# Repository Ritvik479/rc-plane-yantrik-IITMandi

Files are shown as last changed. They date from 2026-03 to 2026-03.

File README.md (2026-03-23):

# ✈️ Garuda 2.0 — RC Plane Design

> Fixed-wing RC aircraft designed for payload delivery, built by **Team Garuda** under the **Yantrik Club, IIT Mandi**.

---

## 📌 Overview

Garuda 2.0 is a high-wing monoplane with a conventional tail, designed for stability and payload delivery. The design philosophy prioritizes a balance between payload capacity and structural rigidity. The **CH-10 airfoil** was selected for its superior lift characteristics at low speeds, and the streamlined rectangular fuselage minimizes drag while housing a 250g cube payload internally.

Visit Official Webpage at : https://remandey.github.io/yantrik-rcplane/

---

## 📐 Technical Specifications

### Dimensions

| Component | Parameter | Value |
|---|---|---|
| **Wing** | Span | 1.18 m |
| **Wing** | Chord | 0.28 m |
| **Wing** | Dihedral | 3° |
| **Fuselage** | Length | 0.9 m |
| **Fuselage** | Width × Height | 0.13 m × 0.13 m |
| **Horizontal Tail** | Span | 0.52 m |
| **Horizontal Tail** | MAC | 0.1305 m |
| **Vertical Tail** | Height | 0.19 m |
| **Vertical Tail** | MAC | 0.0963 m |
| **All-Up Weight** | (without payload) | ~921 g |

### Propulsion System

| Component | Specification | Justification |
|---|---|---|
| Motor | 1500 KV BLDC | High torque for cargo lift |
| ESC | 40A Brushless | Reliable current handling for 3S |
| Battery | 3S LiPo, 2200 mAh (11.1V) | Optimal weight-to-energy ratio |
| Propeller | 1100 × 6 | Matched to motor KV and 3S voltage |

---

## 📊 Design Calculations

| Parameter | Value |
|---|---|
| **Airfoil** | CH-10 |
| **Thrust-to-Weight Ratio** | 1.1 (with payload) / 0.9 (without payload) |
| **Wing Loading** | ~4.19 kg/m² (~41 N/m²) |
| **CG Position** | 25–30% of wing MAC (70–84 mm from LE) |
| **Static Margin** | ~10% (positive longitudinal stability) |

---

## 📦 Payload System

- **Payload:** 250g cube, housed in a balsa cage centered at the CG
- **Drop Mechanism:** RC-operated trap door driven by a high-torque 9g servo
- **Retention:** Push springs at the roof of the cage for smooth ejection

The payload bay is positioned exactly at the aircraft's CG to ensure flight stability is unaffected during and after the drop.

---

## 🧱 Materials & Construction

| Part | Material |
|---|---|
| Fuselage skin | Depron foam |
| Wing ribs | Laser-cut Balsa |
| Wing main spar | Balsa wood (bending stiffness) |
| Wing mounting | Rubber bands (crash-repair friendly) |

---

## 🛠️ Tools & Software

| Tool | Purpose |
|---|---|
| [SolidWorks](https://www.solidworks.com/) | 3D CAD modelling of airframe and components |
| [OpenVSP](http://openvsp.org/) | Aerodynamic geometry and performance analysis |
| [XFLR5](http://www.xflr5.tech/xflr5.htm) | Airfoil selection and wing aerodynamics |

---

## 📸 Construction Photos & CAD Files

📁 [Google Drive — Photos & CAD](https://drive.google.com/drive/folders/1Txp1gwdNweSBexzmWJwU87oO0N__N0AG?usp=sharing)

---

## 🤝 Acknowledgements

Developed under the **Yantrik Club** at **IIT Mandi** .

---

## 📄 License

This project is intended for academic and educational use.  
© Team Garuda — Yantrik Club, IIT Mandi

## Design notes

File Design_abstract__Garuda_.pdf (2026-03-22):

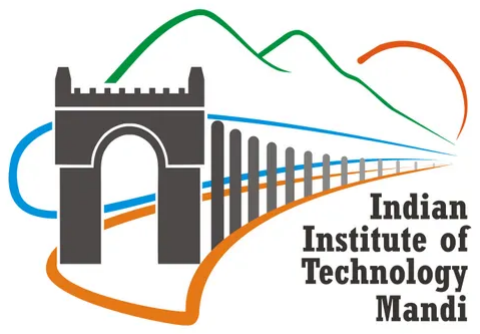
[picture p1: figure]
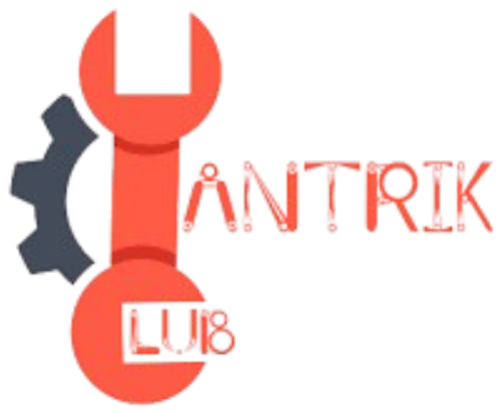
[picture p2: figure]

# DESIGN REPORT : TEAM GARUDA

Team Name: Garuda

Aircraft Name: Garuda 2.0

Team member details

Name | Phone no. | Email ID | Institution
Advaith S. Pillai (Leader) | 8108560164 | b25314@students.iit-mandi.ac.in | IIT Mandi
Reman Dey | 9674300416 | b25331@students.iit-mandi.ac.in | IIT Mandi
Rishi Kurup | 7306000420 | b25394@students.iit-mandi.ac.in | IIT Mandi
Gaurav Gupta | 9835510837 | b25453@students.iit-mandi.ac.in

IIT Mandi

Team Leader Email: b25314@students.iitmandi.ac.in

Team Leader Phone Number: 8108560164

Contents

1 Design Overview | 1
2 Technical Specifications | 1
3 Design Calculations | 2
4 Payload System Design | 2
5 Materials and Construction | 3
6 Competition Strategy | 3
7 Construction Photos and CAD File | 3

i

### 1 DESIGN OVERVIEW

### 1.1 Aircraft configuration type

The aircraft utilizes a high-wing monoplane configuration with a conventional tail. This layout was

chosen for its inherent longitudinal stability and self-righting tendencies, which are critical for main-

taining a steady flight path during payload delivery missions.

### 1.2 Overall design concept

Our design philosophy prioritizes a balance between payload capacity and structural rigidity. Using

an iterative approach, we selected the CH-10 airfoil for its superior lift characteristics at low speeds.

The fuselage is designed as a streamlined rectangular box to minimize drag while providing a large

internal volume for the 250g cube payload.

### 1.3 How our design addresses the competition requirements

- Dimensions: The 1.18 m wingspan and 0.9m length comply with all AeroVerse size con-

straints.

- Payload: The internal bay is centered exactly at the CG to ensure stability remains unaffected

during the drop.

- Safety: The high-wing placement and 3-degree dihedral ensure a high static margin for safe

operation.

### 2 TECHNICAL SPECIFICATIONS

- Wingspan: 1.18 m
- Aircraft weight without payload: ≈ 921 g
- Propeller diameter: 11⁰⁰ × 6
- Motor specifications: 1500KV BLDC Motor
- Battery details: 3S 2200mAh LiPo (11.1V)

### 2.1 Dimensions

1. Fuselage: L : 0.9m, W : 0.13m, H : 0.13m
2. Wing: Span: 1.18m, Chord: 0.28m, Dihedral: 3

◦

3. Tail (Horizontal): Span: 0.52m, MAC: 0.1305m
4. Tail (Vertical): Height: 0.19m, MAC: 0.0963m

### 2.2 Propulsion System

Component | Specification | Justification
Motor | 1500KV BLDC | High torque for cargo lift
ESC | 40A Brushless | Reliable current handling for 3S
Battery | 3S LiPo (2200 mAh) | Optimal weight-to-energy ratio

### 3 DESIGN CALCULATIONS

- Thrust-to-Weight Ratio: Calculated at 1.1 (with payload) and 0.9 (without payload), ensuring

climb performance.

- Wing Loading: 4.19 kg/m²

(approx. 41 N/m²
), allowing for a very low stall speed.
- Airfoil Selection: CH-10. Chosen for high CL and predictable stall behavior in cargo-lift ap-

plications.

- Center of Gravity (CG): Positioned at 25% − 30% of the wing MAC (70mm − 84mm from

LE).

- Static Margin: ≈ 10%, providing positive longitudinal stability.

### 4 PAYLOAD SYSTEM DESIGN

### 4.1 Payload compartment design

The compartment is a balsa cage structure designed to house a 250g cube with push springs at-

tached at the roof of the cage for ease of drop.

### 4.2 RC-operated mechanism

A high-torque 9g servo operates a trap door mechanism which opens and drops the payload inside

it.

### 5 MATERIALS AND CONSTRUCTION

- Fuselage: Depron foam skin.
- Wing: Laser-cut Balsa ribs with a Balsa wood main spar for bending stiffness.
- Assembly: The wing is mounted via rubber bands to the fuselage ease of operation and

crash-repair ease.

### 6 COMPETITION STRATEGY

- Qualifier Round: Focus on maximum flight time and stability with the 250g payload.
- Main Round: Prioritizing precision in the drop zone by timing the release based on ground-

speed estimates.

- Safety: Pre-flight checks include range testing and verification of the fail-safe return-to-home

protocol.

### 7 CONSTRUCTION PHOTOS AND CAD FILE

## https://drive.google.com/drive/folders/1Txp1gwdNweSBexzmWJwU87oO0N__N0AG?usp=sharing

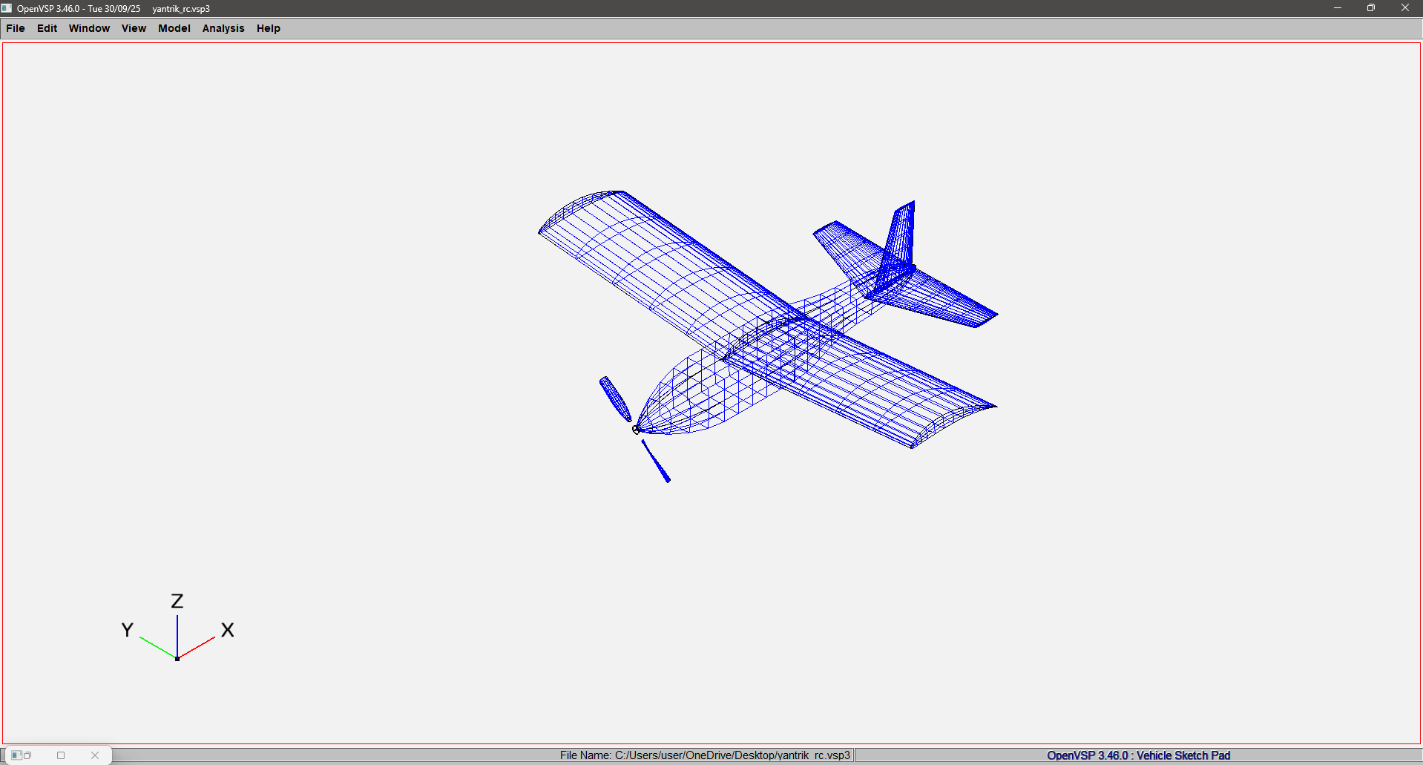
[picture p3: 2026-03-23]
Simulations/wireframe_view.png

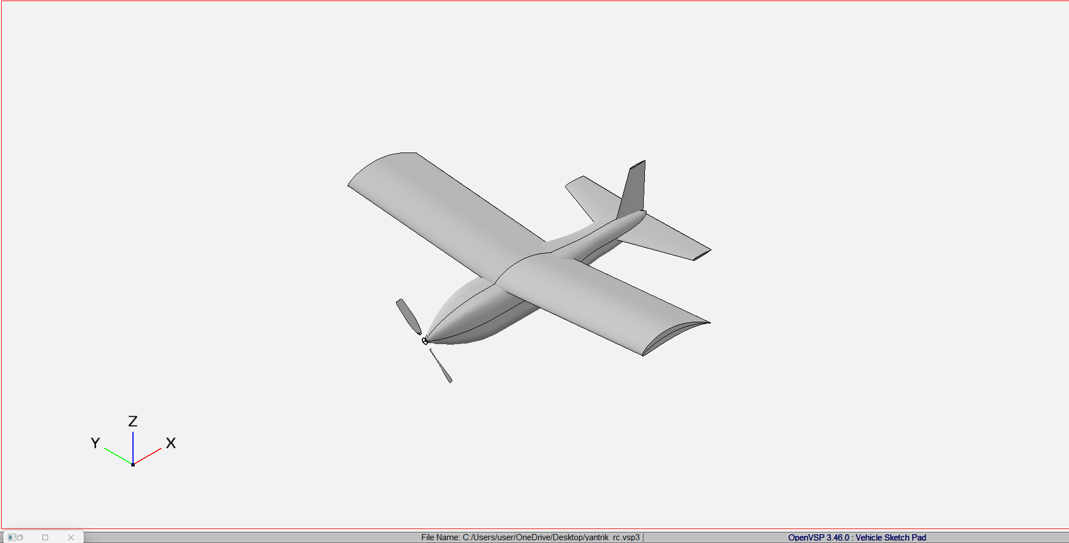
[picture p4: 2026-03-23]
Simulations/Solid_view.png

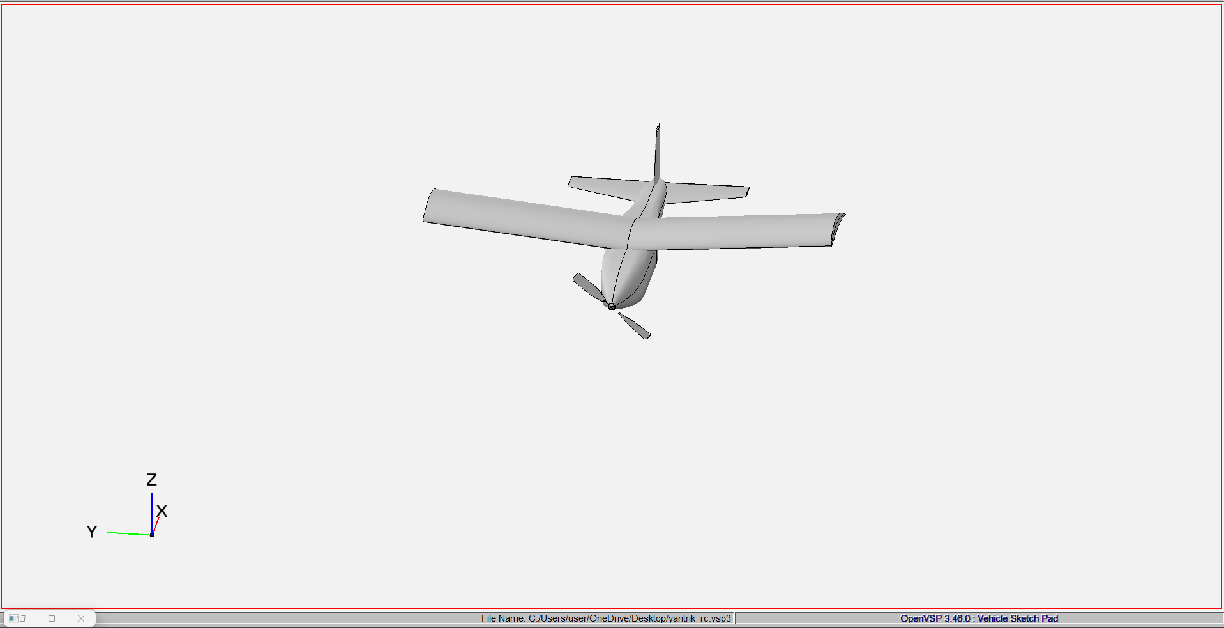
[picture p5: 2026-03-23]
Simulations/frontal_view.png

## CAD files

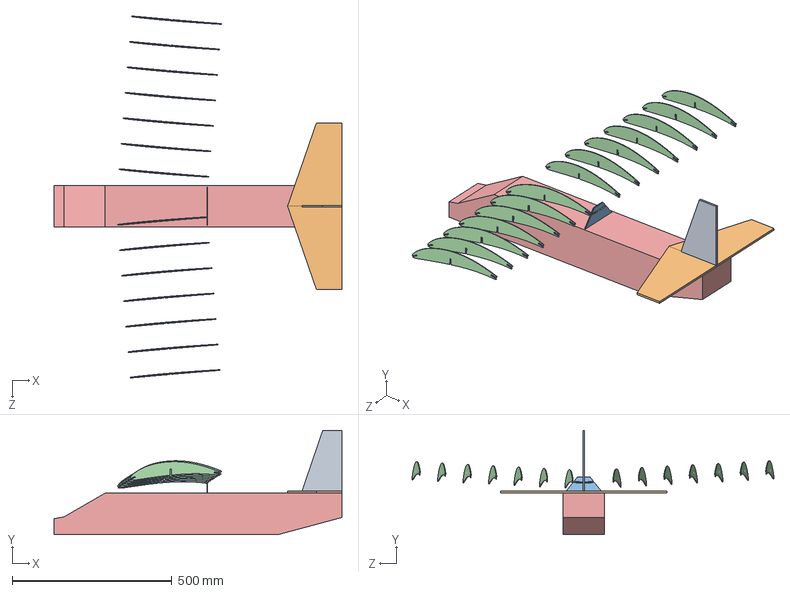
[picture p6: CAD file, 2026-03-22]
final-assembly/Final Plane Assembly.SLDASM
900.0 x 326.0 x 1131.8 mm
Fuselage3 - Copy
Airfoil x 14
Brace2
Horizontal Tail2 x 2
Vertical Tail2

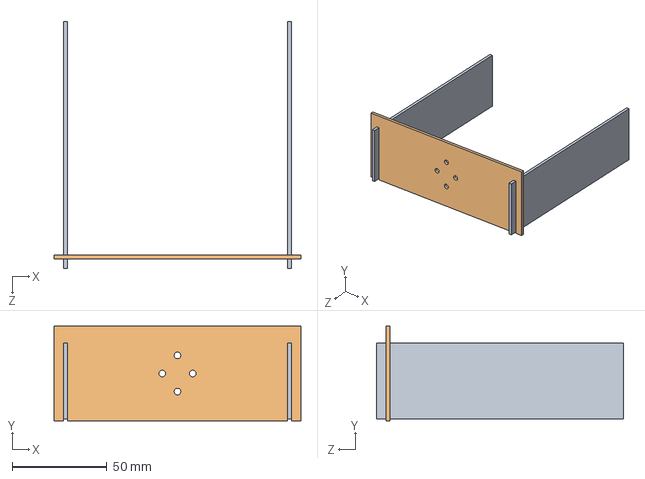
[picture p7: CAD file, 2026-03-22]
motor-mount/Motor Mount.SLDASM
130.0 x 50.0 x 130.0 mm

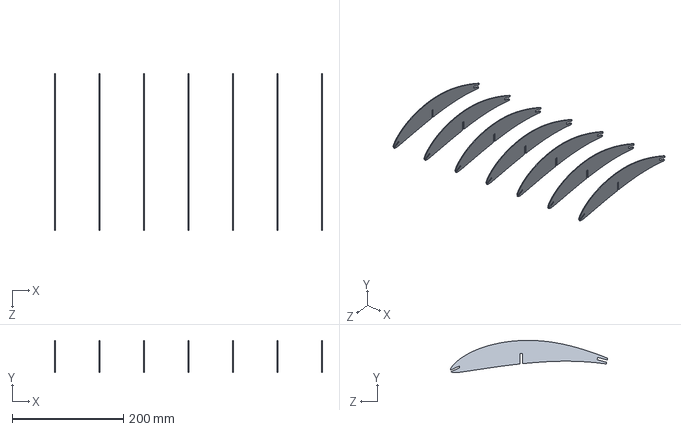
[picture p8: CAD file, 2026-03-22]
final-assembly/Final Wing Assembly.SLDASM
482.0 x 58.1 x 283.3 mm
Airfoil x 7

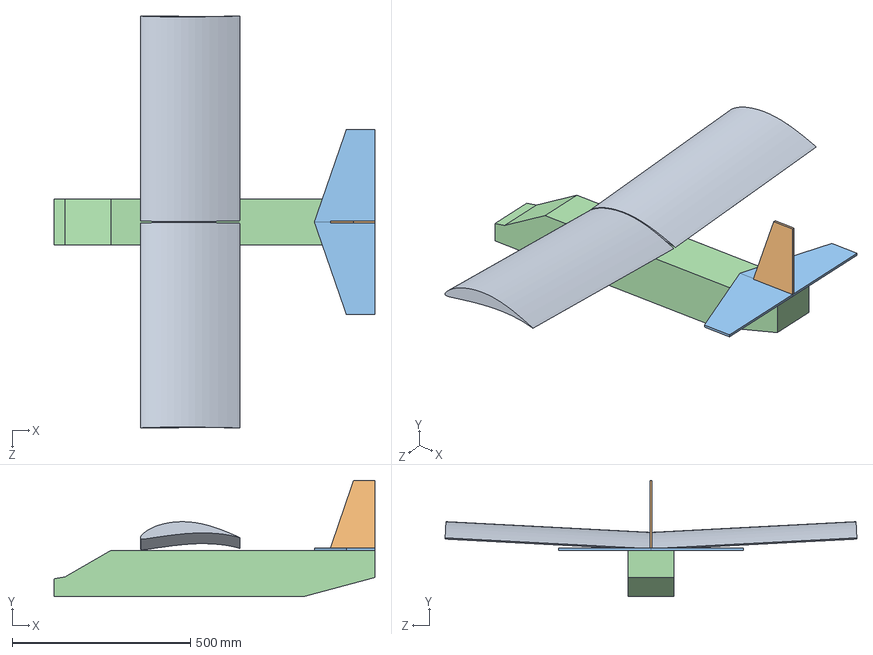
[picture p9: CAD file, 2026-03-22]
alt-assembly/Alternative Plane Assembly.SLDASM
900.0 x 326.0 x 1155.9 mm
Fuselage3 - Copy
Horizontal Tail2 x 2
Vertical Tail2
Wing2 x 2

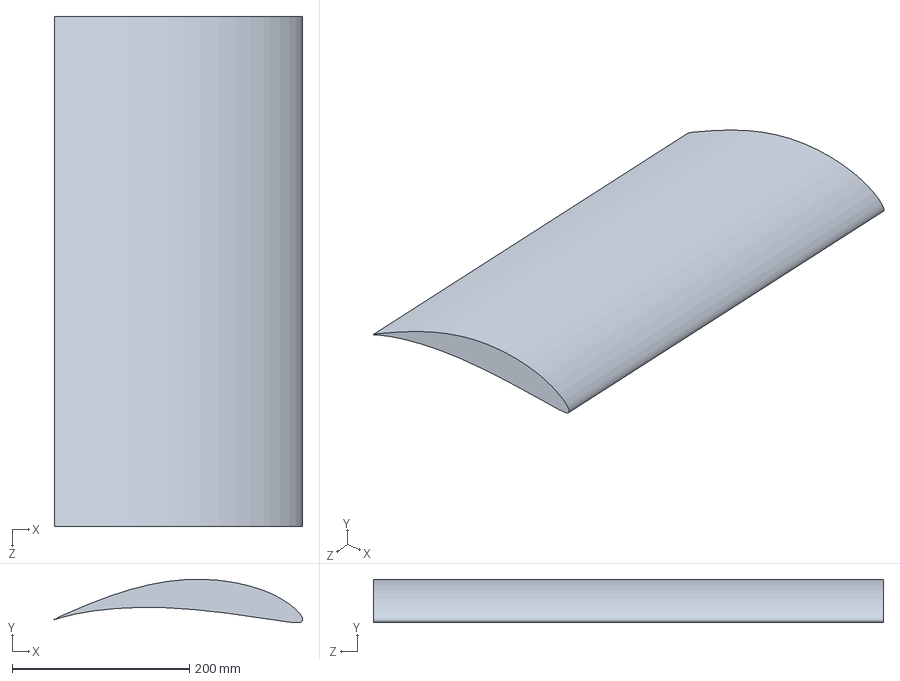
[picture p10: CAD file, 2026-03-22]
alt-assembly/Wing2.SLDPRT
280.0 x 49.0 x 575.0 mm

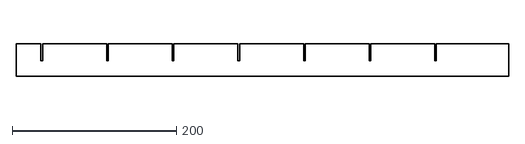
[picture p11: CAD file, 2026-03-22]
laser-cut-files/spar.dxf
600.0 x 40.0

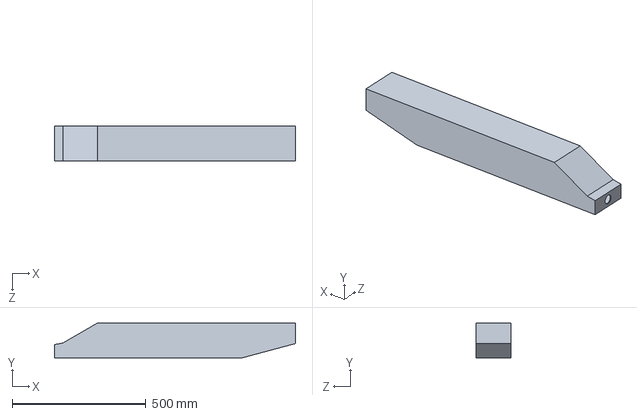
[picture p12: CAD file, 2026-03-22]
alt-assembly/Fuselage3 - Copy.SLDPRT
900.0 x 130.0 x 130.0 mm

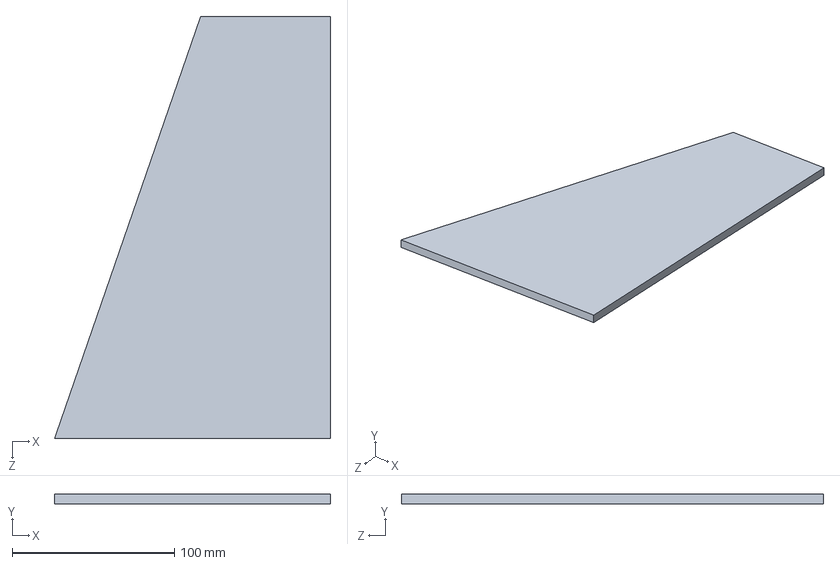
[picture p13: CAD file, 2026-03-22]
final-assembly/Horizontal Tail2.SLDPRT
170.0 x 6.00 x 260.0 mm

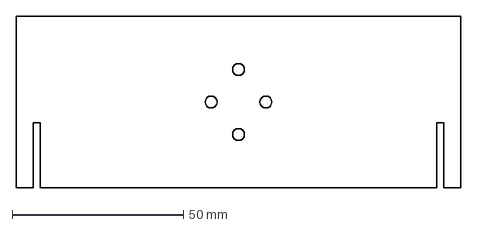
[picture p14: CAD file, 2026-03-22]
laser-cut-files/Part1.DXF
130.0 x 50.0 mm

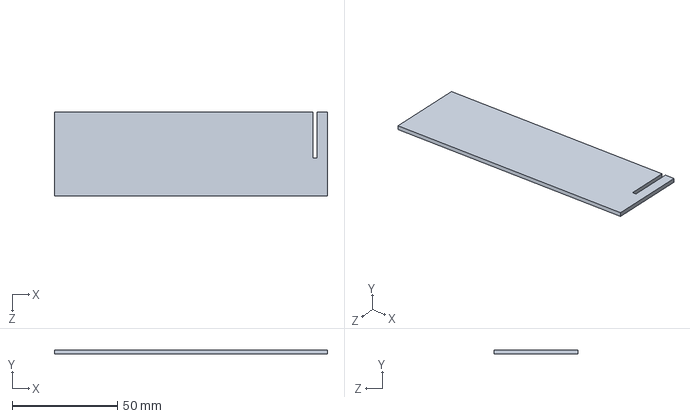
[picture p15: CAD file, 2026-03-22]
motor-mount/Part2.SLDPRT
130.0 x 2.00 x 40.0 mm

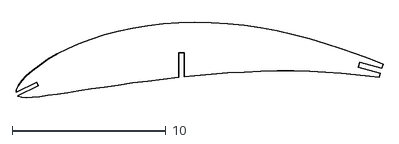
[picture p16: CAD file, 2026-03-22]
laser-cut-files/airfoil ct.dxf
23.9 x 4.90

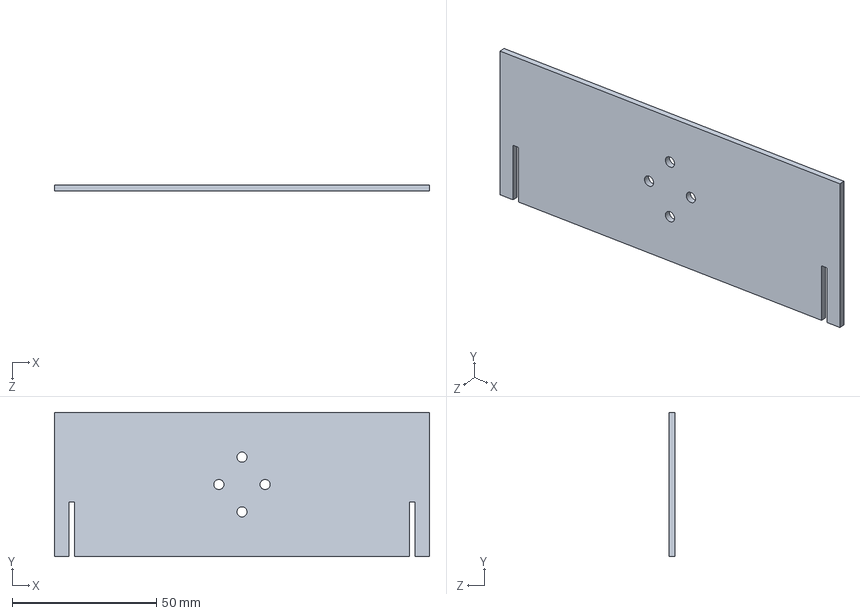
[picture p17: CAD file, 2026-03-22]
motor-mount/Part1.SLDPRT
130.0 x 50.0 x 2.00 mm

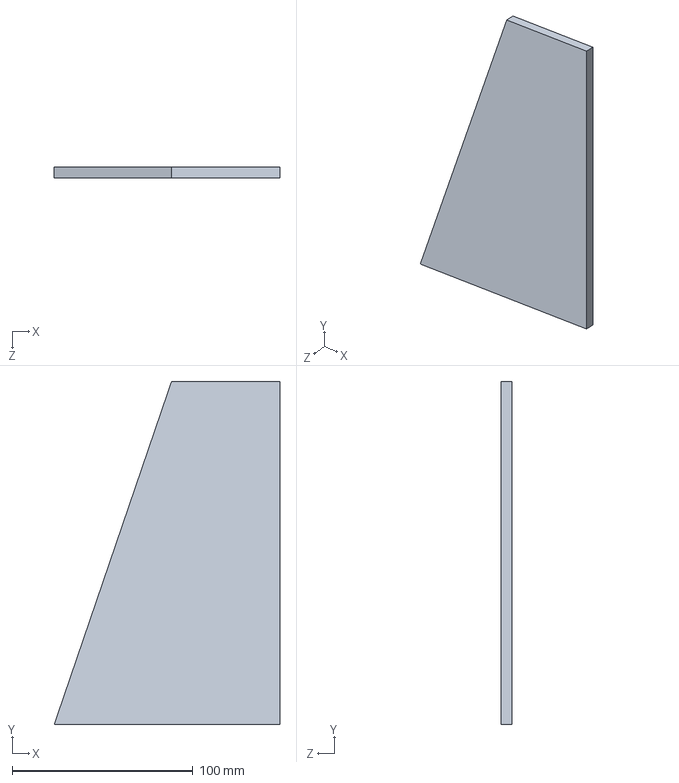
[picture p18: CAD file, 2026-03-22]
alt-assembly/Vertical Tail2.SLDPRT
125.0 x 190.0 x 6.00 mm

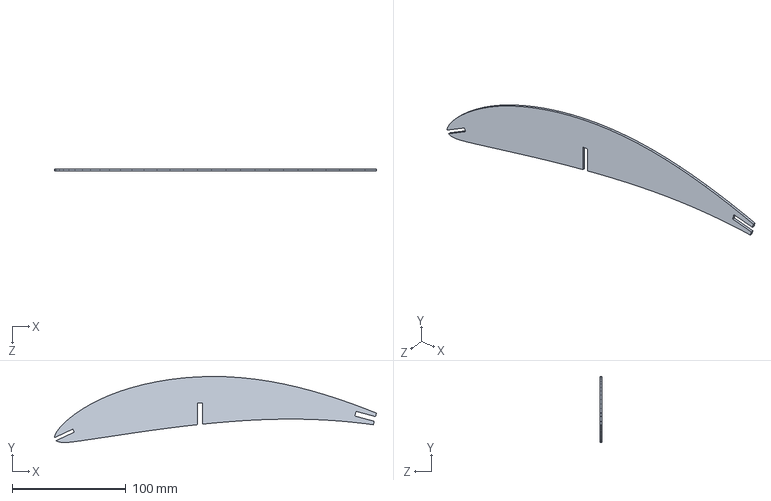
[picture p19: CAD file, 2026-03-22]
final-assembly/Airfoil.SLDPRT
283.3 x 58.1 x 2.00 mm

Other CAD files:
laser-cut-files/BraceBack.DXF
final-assembly/Brace2.SLDPRT
laser-cut-files/Part2.DXF
alt-assembly/motor.SLDPRT
final-assembly/Back Spar.SLDPRT
final-assembly/Brace.SLDPRT
final-assembly/Spar.SLDPRT
final-assembly/motor.SLDPRT
laser-cut-files/BraceFront.DXF
laser-cut-files/backk spar.dxf

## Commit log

2026-03-22 Initial commit: RC aircraft CAD files
    [Airfoil.SLDPRT, Alternative Plane Assembly.SLDASM, Back Spar.SLDPRT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]
2026-03-22 Add .dxf files for laser cutting
    [BraceBack.DXF, BraceFront.DXF, Part1.DXF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]
2026-03-22 Create README.md for laser-cut-files
2026-03-22 Add .dxf to laser-cut-files/
    [BraceBack.DXF, BraceFront.DXF, Part1.DXF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]
2026-03-22 Remove README.md from laser-cut-files
    [BraceBack.DXF, BraceFront.DXF, Part1.DXF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]
2026-03-23 Revise README for Garuda 2.0 RC Plane Project
    Updated the README to reflect the new project name and added technical specifications, payload system details, and construction materials.
